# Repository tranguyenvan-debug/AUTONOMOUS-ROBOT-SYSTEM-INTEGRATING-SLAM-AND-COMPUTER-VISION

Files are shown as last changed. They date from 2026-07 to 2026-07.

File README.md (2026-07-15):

# 🤖 Autonomous Robot System Integrating SLAM and Computer Vision

**Final Year Project (Đồ Án 2)** — Ho Chi Minh City University of Technology (HCMUT)

Bachelor of Engineering in Electronics and Telecommunications

**Student:** Nguyen Van Tra

**Supervisor:** Assoc. Prof. Dr. Ha Hoang Kha

**Year:** 2026

**Achievement:** 9/10






---

## 📋 Overview

An indoor autonomous mobile robot system built on **ROS2 Jazzy**, integrating:

- 🗺️ **SLAM** — Real-time 360° environment mapping via LiDAR
- 📍 **Localization** — Robot positioning on saved maps (AMCL)
- 🚗 **Navigation** — Autonomous waypoint navigation with obstacle avoidance (Nav2)
- 👁️ **Computer Vision** — Object detection and visual servoing (YOLOv8n)
- 🌐 **Web Dashboard** — Browser-based monitoring and control via WiFi

Prototyte

3D

2D

Web

TFtree

Tele

Schematic

Map

Map_Web

AI

---

## 🖼️ Hardware Gallery

<div align="center">

| Component | Image |
|:---:|:---:|
| Raspberry Pi 4 (4GB) | Pi4 |
| ESP32 DevKit v1 | ESP32 |
| RPLidar A1M8 | LiDAR A1M8 |
| Raspberry Pi Camera V2 | Camera Pi V2 |
| MPU6050 IMU | IMU |
| JGB37-520 Motor w/ Encoder | JGB37-520-Encoder |
| L298N Motor Driver | Drive L298N |
| Buck DC-DC | Buck DC |
| BMS | BMS |
| 12V Power (3S 18650) |  |

</div>

---

## 🔧 Hardware Components

<div align="center">

| Component | Model | Role |
|:---:|:---:|:---:|
| Embedded Computer | Raspberry Pi 4 (4GB RAM) | ROS2, SLAM, Nav2, AI processing |
| Microcontroller | ESP32 DevKit v1 | PID motor control, Odometry |
| LiDAR | RPLidar A1M8 | 360° environment scanning, 12m range |
| Camera | Raspberry Pi Camera V2 | Video stream, object detection |
| IMU | MPU6050 | Acceleration & angular velocity |
| Motors | JGB37-520 12V w/ Encoder | Differential drive |
| Motor Driver | L298N H-Bridge | DC motor control |
| Power | 12V 18650 Battery | Main power supply |

</div>

---

## 🔌 Pin Wiring Table

### ESP32 → L298N (Motor Driver)

<div align="center">

| ESP32 Pin | L298N Pin | Description |
|:---:|:---:|:---:|
| GPIO 25 | IN1 | Left motor direction A |
| GPIO 26 | IN2 | Left motor direction B |
| GPIO 27 | IN3 | Right motor direction A |
| GPIO 14 | IN4 | Right motor direction B |
| GPIO 32 | ENA (PWM) | Left motor speed |
| GPIO 33 | ENB (PWM) | Right motor speed |
| GND | GND | Common ground |

</div>

### ESP32 → Encoder (JGB37-520)

<div align="center">

| ESP32 Pin | Encoder Pin | Description |
|:---:|:---:|:---:|
| GPIO 18 | Left Encoder A | Left wheel channel A |
| GPIO 19 | Left Encoder B | Left wheel channel B |
| GPIO 22 | Right Encoder A | Right wheel channel A |
| GPIO 23 | Right Encoder B | Right wheel channel B |
| 3.3V | VCC | Encoder power |
| GND | GND | Common ground |

</div>

### Raspberry Pi 4 → MPU6050 (I2C)

<div align="center">

| Raspberry Pi Pin | MPU6050 Pin | Description |
|:---:|:---:|:---:|
| Pin 1 (3.3V) | VCC | Power supply |
| Pin 6 (GND) | GND | Ground |
| Pin 3 (GPIO 2, SDA) | SDA | I2C data |
| Pin 5 (GPIO 3, SCL) | SCL | I2C clock |
| — | AD0 | Left floating → address 0x68 |

</div>

### Raspberry Pi 4 → Other Peripherals

<div align="center">

| Raspberry Pi | Device | Interface |
|:---:|:---:|:---:|
| USB Port 1 | ESP32 | USB Serial (/dev/ttyESP32) |
| USB Port 2 | RPLidar A1M8 | USB Serial (/dev/ttyLIDAR) |
| CSI Camera Port | Pi Camera V2 | CSI Ribbon Cable |

</div>

---

## 💻 Software Stack

<div align="center">

| Component | Technology |
|:---:|:---:|
| OS | Ubuntu 24.04 (Raspberry Pi) |
| Framework | ROS2 Jazzy |
| SLAM | SLAM Toolbox (Graph-based SLAM) |
| Localization | AMCL (Adaptive Monte Carlo) |
| Navigation | Nav2 Stack (MPPI + NavFn/A*) |
| Sensor Fusion | EKF (robot_localization) |
| AI Model | YOLOv8n ONNX (80 classes, COCO) |
| Web Frontend | HTML/JavaScript + roslibjs |
| Web Backend | Python HTTP Server |
| Notification | Telegram Bot API |

</div>

---

## 📁 Project Structure

```
robot_project/
├── robot_ws/src/robot_base/
│   ├── robot_base/
│   │   ├── serial_bridge.py        # ESP32 communication via Serial USB
│   │   ├── imu_publisher.py        # MPU6050 IMU reading via I2C
│   │   ├── camera_publisher.py     # Pi Camera V2 stream (OpenCV)
│   │   └── yolo_detector.py        # YOLOv8n detection + Visual Servoing
│   ├── launch/
│   │   ├── slam.launch.py          # Boot: start base nodes
│   │   ├── slam_only.launch.py     # SLAM Toolbox (mapping mode)
│   │   └── nav2_only.launch.py     # Nav2 Stack (navigation mode)
│   └── config/
│       ├── ekf.yaml                # Extended Kalman Filter config
│       ├── slam.yaml               # SLAM Toolbox parameters
│       └── nav2_params.yaml        # Nav2 config (AMCL, costmap, planner)
├── robot_web/
│   ├── backend.py                  # HTTP server (port 8080)
│   └── index.html                  # Web Dashboard
├── maps/                           # Saved maps (.pgm, .yaml, waypoints.json)
├── yolov8n.onnx                    # AI model (12.7MB)
├── run_slam.sh                     # SLAM startup script
├── run_nav2.sh                     # Nav2 startup script
├── send_ip.sh                      # Send IP via Telegram on boot
├── docs/images/                    # Hardware photos (add yours here)
└── /etc/
    ├── systemd/system/
    │   ├── robot-ros.service       # Auto-start ROS2 on boot
    │   └── robot-web.service       # Auto-start Web Dashboard on boot
    └── udev/rules.d/
        └── 99-robot.rules          # Fixed port symlinks for ESP32 & LiDAR
```

---

## ⬇️ Download

### Option 1 — Download from GitHub Releases (Recommended)

1. Go to the [**Releases**](../../releases) tab on GitHub
2. Download the latest `.zip` file (e.g. `AUTONOMOUS-ROBOT-SYSTEM-INTEGRATING-SLAM-AND-COMPUTER-VISION-1.0.0.zip`)
3. Extract and follow the installation steps below

### Option 2 — Clone via Git

```bash
git clone https://github.com/tranguyenvan-debug/AUTONOMOUS-ROBOT-SYSTEM-INTEGRATING-SLAM-AND-COMPUTER-VISION
cd AUTONOMOUS-ROBOT-SYSTEM-INTEGRATING-SLAM-AND-COMPUTER-VISION-1.0.0
```

### Option 3 — Download ZIP directly

Click **Code → Download ZIP** at the top of this page.

---

## 🚀 Installation

### Requirements

- Raspberry Pi 4 (Ubuntu 24.04)
- ROS2 Jazzy
- Python 3.12+

### 1. Install ROS2 Jazzy

```bash
# Follow official guide
https://docs.ros.org/en/jazzy/Installation/Ubuntu-Install-Debs.html
```

### 2. Install dependencies

```bash
sudo apt install -y \
  ros-jazzy-slam-toolbox \
  ros-jazzy-nav2-bringup \
  ros-jazzy-robot-localization \
  ros-jazzy-rosbridge-server \
  ros-jazzy-rplidar-ros \
  ros-jazzy-nav2-mppi-controller

pip install onnxruntime opencv-python smbus2 pyserial --break-system-packages
```

### 3. Clone and build

```bash
mkdir -p ~/robot_ws/src
cd ~/robot_ws/src
git clone https://github.com/tranguyenvan-debug/AUTONOMOUS-ROBOT-SYSTEM-INTEGRATING-SLAM-AND-COMPUTER-VISION
cd ~/robot_ws
colcon build --packages-select robot_base
source install/setup.bash
```

### 4. Setup udev rules (fixed serial ports)

```bash
sudo cp etc/udev/rules.d/99-robot.rules /etc/udev/rules.d/
sudo udevadm control --reload-rules && sudo udevadm trigger
# Verify: ls -la /dev/ttyESP32 /dev/ttyLIDAR
```

### 5. Install systemd services (auto-boot)

```bash
sudo cp etc/systemd/system/robot-ros.service /etc/systemd/system/
sudo cp etc/systemd/system/robot-web.service /etc/systemd/system/
sudo systemctl enable robot-ros.service robot-web.service
sudo systemctl start robot-ros.service robot-web.service
```

### 6. Configure Telegram Bot (receive IP on boot)

Edit `send_ip.sh`:
```bash
TOKEN="your_bot_token_here"
CHAT_ID="your_chat_id_here"
```

Get your token from [@BotFather](https://t.me/botfather) on Telegram.

---

## 📖 Usage

### Access Web Dashboard

```
http://<raspberry_pi_ip>:8080
```

> 💡 The robot sends its IP to your Telegram on every boot — no need to check manually.

### Operating Flow

```
1. Power on Pi → services auto-start → receive IP via Telegram
2. Open Web Dashboard in browser
3. Tab [Mapping]:
   - Click "Start SLAM"
   - Drive robot around the room using joystick
   - Click "Save Map" → enter name → "Stop SLAM"
4. Tab [Navigation]:
   - Click "Start Nav2" (wait ~30s for initialization)
   - Click "Set Initial Pose" (place robot at starting position)
   - Save waypoints → click any waypoint to start autonomous navigation
5. Tab [AI]:
   - Click "Start AI"
   - Camera shows real-time object detection
   - Click object name to activate visual servoing (robot follows target)
```

---

## 🌐 Web Dashboard

<div align="center">

| Tab | Features |
|:---:|:---:|
| **Mapping** | Real-time SLAM map, joystick control, emergency stop, save map |
| **Navigation** | Autonomous waypoint navigation, robot position on map, camera feed |
| **AI** | Live camera, YOLOv8n detection overlay, visual servoing target selection |
| **History** | Trip log, obstacle count, distance traveled, system stats |

</div>

### Backend API Endpoints

<div align="center">

| Endpoint | Description |
|:---:|:---:|
| `GET /slam/start` | Start SLAM mapping |
| `GET /slam/stop` | Stop SLAM |
| `GET /nav2/start` | Start Nav2 (loads latest map) |
| `GET /nav2/stop` | Stop Nav2 |
| `GET /map/save?name=X` | Save current map |
| `GET /waypoint/save` | Save current position as waypoint |
| `GET /waypoint/list` | List all waypoints for current map |
| `GET /waypoint/delete` | Delete a waypoint |
| `GET /ai/start` | Start YOLO detector |
| `GET /ai/stop` | Stop YOLO detector |
| `GET /set_initial_pose` | Publish initial pose to AMCL |
| `GET /sysinfo` | CPU / RAM / Disk / WiFi stats |
| `GET /status` | SLAM / Nav2 running status |

</div>

---

## 📊 Technical Specifications

### AI Model — YOLOv8n

<div align="center">

| Parameter | Value |
|:---:|:---:|
| Model | YOLOv8n (Nano) |
| Format | ONNX Runtime |
| Number of classes | 80 (COCO dataset) |
| Model size | 12.7 MB |
| mAP50 (COCO) | 37.3% |
| mAP50-95 (COCO) | 52.9% |
| FPS on Raspberry Pi 4 | ~0.3–0.5 FPS |
| Confidence threshold | 0.4 |
| IoU threshold (NMS) | 0.45 |

</div>

### Navigation — Nav2

<div align="center">

| Parameter | Value |
|:---:|:---:|
| Global Planner | NavFn (A*) |
| Local Planner | MPPI Controller |
| Robot radius | 0.15 m |
| Inflation radius | 0.2 m |
| Max linear velocity | 0.2 m/s |
| Goal tolerance | 0.5 m |
| Map resolution | 0.02 m/pixel |

</div>

### LiDAR — RPLidar A1M8

<div align="center">

| Parameter | Value |
|:---:|:---:|
| Range | 0.15 — 12 m |
| Scan frequency | ~5.5 Hz (360°/revolution) |
| Points per scan | ~1,450 points |
| Interface | USB Serial |

</div>

---

## 🐛 Debugging

```bash
# Check running nodes
ros2 node list

# Check SLAM status
ros2 lifecycle get /slam_toolbox

# Check AMCL pose
ros2 topic echo /amcl_pose --once

# Check LiDAR data rate
ros2 topic hz /scan

# View service logs
sudo journalctl -u robot-ros.service -f
sudo journalctl -u robot-web.service -f

# Restart all services
sudo systemctl restart robot-ros.service robot-web.service

# Fix port conflict (rosbridge)
sudo fuser -k 9090/tcp

# Check CPU load
top -bn1 | head -5
```

---

## 📚 References

- [ROS2 Jazzy Documentation](https://docs.ros.org/en/jazzy/)
- [Nav2 Documentation](https://docs.nav2.org/)
- [SLAM Toolbox](https://slam-toolbox.readthedocs.io/)
- [YOLOv8 — Ultralytics](https://docs.ultralytics.com/models/yolov8/)
- [ONNX Runtime](https://onnxruntime.ai/docs/)
- [Probabilistic Robotics — Thrun, Burgard, Fox](http://www.probabilistic-robotics.org/)
- [Telegram Bot API](https://core.telegram.org/bots/api)

---

## 📄 License

MIT License — Free to use for educational and research purposes.

---

## ⭐ Support This Project

If this project helped you or inspired your own robot build, please consider giving it a **star** ⭐ on GitHub — it means a lot and helps others discover this project!

<div align="center">

**Made with ❤️ by [nguyenvantra-debug](https://github.com/nguyenvantra-debug) (Văn Trà)**

*Ho Chi Minh City University of Technology (HCMUT) | Bachelor of Engineering in Electronics and Telecommunications | 2026*

</div>

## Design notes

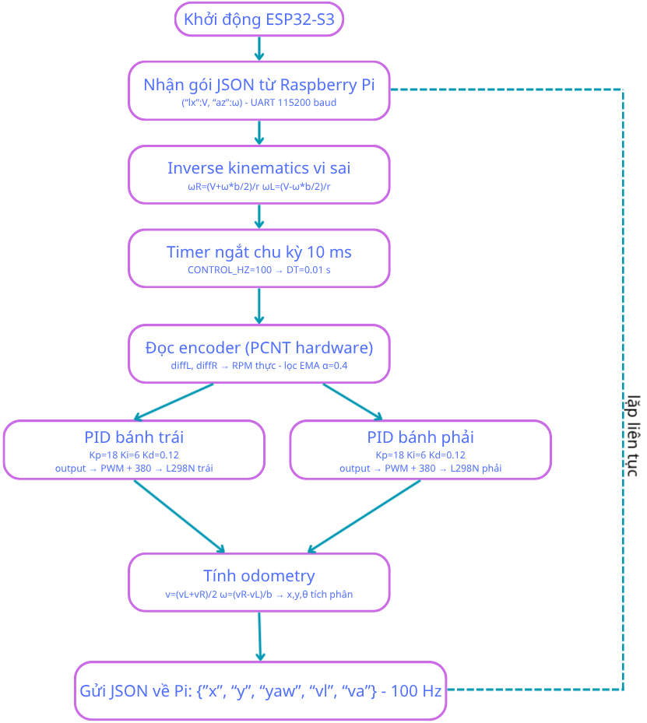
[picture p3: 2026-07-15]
System Block Diagram/Picture7.png

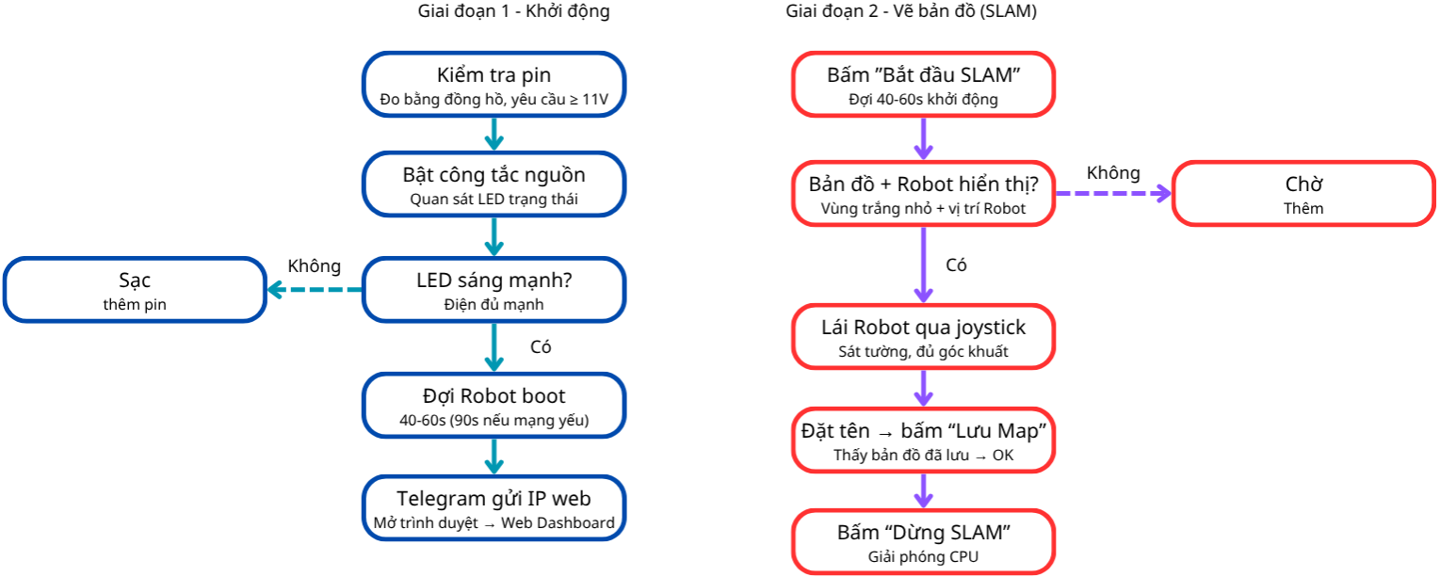
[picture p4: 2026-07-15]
System Block Diagram/Picture11.png

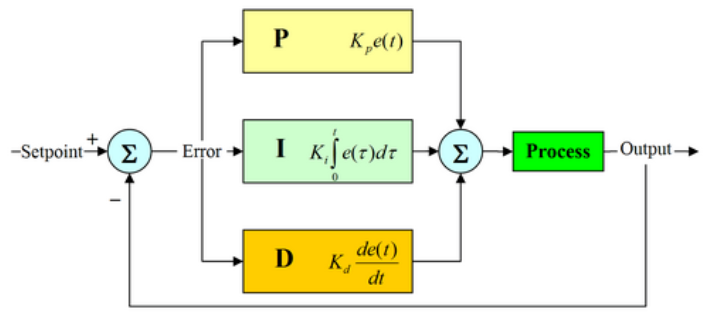
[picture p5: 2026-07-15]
System Block Diagram/Picture2.png

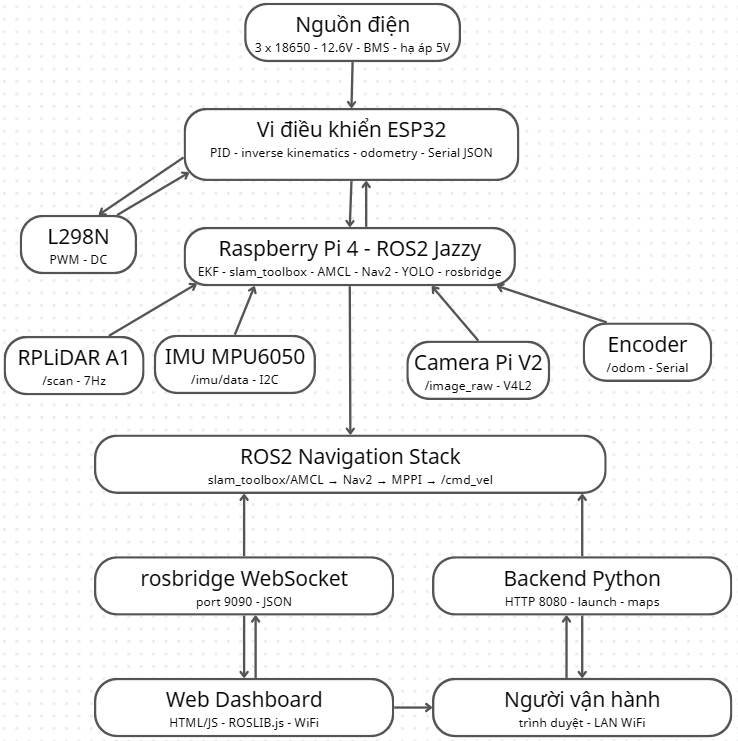
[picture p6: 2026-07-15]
System Block Diagram/Picture4.png

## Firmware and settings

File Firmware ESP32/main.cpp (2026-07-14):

#include <Arduino.h>
#include <ArduinoJson.h>
#include <ESP32Encoder.h>

// ================= PIN =================
#define L_IN1 5
#define L_IN2 6
#define L_PWM 4

#define R_IN1 15
#define R_IN2 7
#define R_PWM 16

#define L_A 9
#define L_B 8
#define R_A 11
#define R_B 10

#define LED_PIN 2

#define PWM_FREQ 800
#define PWM_RES 10
#define PWM_MAX 1023
#define PWM_MIN 380

#define L_CH 0
#define R_CH 1

// ================= ROBOT =================
const float wheel_diameter = 0.065;
const float wheel_base = 0.18;
const float wheel_circ = PI * wheel_diameter;

const float PPR_L = 10800.0;
const float PPR_R = 11330.0;

// ================= CONTROL =================
#define CONTROL_HZ 100
#define DT (1.0 / CONTROL_HZ)

// ================= ENCODER =================
ESP32Encoder encL;
ESP32Encoder encR;

long prevTickL = 0;
long prevTickR = 0;

// ================= CMD =================
float cmd_v = 0;
float cmd_w = 0;

float cmd_v_ramp = 0;
float cmd_w_ramp = 0;

uint32_t lastCmd = 0;
const uint32_t timeout = 500;

// ================= TARGET RPM =================
float targetRPM_L = 0;
float targetRPM_R = 0;

// ================= PID =================
float Kp = 18;
float Ki = 6;
float Kd = 0.12;

float eL = 0, eR = 0;
float prevL = 0, prevR = 0;
float sumL = 0, sumR = 0;

// ================= FILTER =================
float rpmL_f = 0;
float rpmR_f = 0;
const float alpha = 0.4;

// ================= ODOM =================
float x = 0;
float y = 0;
float th = 0;

// ================= MOTOR =================
void setDir(float L, float R) {

  if (L > 0) {
    digitalWrite(L_IN1, LOW);
    digitalWrite(L_IN2, HIGH);
  }
  else if (L < 0) {
    digitalWrite(L_IN1, HIGH);
    digitalWrite(L_IN2, LOW);
  }
  else {
    digitalWrite(L_IN1, LOW);
    digitalWrite(L_IN2, LOW);
  }

  if (R > 0) {
    digitalWrite(R_IN1, LOW);
    digitalWrite(R_IN2, HIGH);
  }
  else if (R < 0) {
    digitalWrite(R_IN1, HIGH);
    digitalWrite(R_IN2, LOW);
  }
  else {
    digitalWrite(R_IN1, LOW);
    digitalWrite(R_IN2, LOW);
  }
}

void setPWM(int L, int R) {

  if (L != 0)
    L = constrain(abs(L) + PWM_MIN, PWM_MIN, PWM_MAX);

  if (R != 0)
    R = constrain(abs(R) + PWM_MIN, PWM_MIN, PWM_MAX);

  ledcWrite(L_CH, L);
  ledcWrite(R_CH, R);
}

// ================= RAMP =================
float ramp(float current, float target, float step) {

  float diff = target - current;

  if (diff > step) diff = step;
  if (diff < -step) diff = -step;

  return current + diff;
}

// ================= RECEIVE CMD =================
void readCmd() {

  if (!Serial.available()) return;

  String json = Serial.readStringUntil('\n');

  StaticJsonDocument<64> doc;

  if (!deserializeJson(doc, json)) {

    cmd_v = doc["lx"] | 0.0;
    cmd_w = doc["az"] | 0.0;

    lastCmd = millis();
  }
}

// ================= VELOCITY =================
void velocityLoop() {

  float step = 0.5 * DT;

  cmd_v_ramp = ramp(cmd_v_ramp, cmd_v, step);
  cmd_w_ramp = ramp(cmd_w_ramp, cmd_w, step);

  float vL = cmd_v_ramp - cmd_w_ramp * wheel_base / 2;
  float vR = cmd_v_ramp + cmd_w_ramp * wheel_base / 2;

  targetRPM_L = (vL / wheel_circ) * 60;
  targetRPM_R = (vR / wheel_circ) * 60;
}

// ================= RPM =================
float calcRPM(long diff, float ppr) {
  return (diff / ppr) * 60.0 * CONTROL_HZ;
}

// ================= CONTROL LOOP =================
void controlLoop() {

  static uint32_t last = 0;

  if (millis() - last < 1000 / CONTROL_HZ)
    return;

  last = millis();

  // ===== EMERGENCY STOP =====
  if (millis() - lastCmd > timeout) {

    cmd_v = 0;
    cmd_w = 0;

    cmd_v_ramp = 0;
    cmd_w_ramp = 0;

    targetRPM_L = 0;
    targetRPM_R = 0;
  }

  long tickL = encL.getCount();
  long tickR = encR.getCount();

  long diffL = tickL - prevTickL;
  long diffR = tickR - prevTickR;

  prevTickL = tickL;
  prevTickR = tickR;

  float rpmL = calcRPM(diffL, PPR_L);
  float rpmR = calcRPM(diffR, PPR_R);

  rpmL_f = alpha * rpmL + (1 - alpha) * rpmL_f;
  rpmR_f = alpha * rpmR + (1 - alpha) * rpmR_f;

  eL = targetRPM_L - rpmL_f;
  eR = targetRPM_R - rpmR_f;

  sumL += eL * DT;
  sumR += eR * DT;

  sumL = constrain(sumL, -200, 200);
  sumR = constrain(sumR, -200, 200);

  float dL = (eL - prevL) / DT;
  float dR = (eR - prevR) / DT;

  float outL = Kp * eL + Ki * sumL + Kd * dL;
  float outR = Kp * eR + Ki * sumR + Kd * dR;

  prevL = eL;
  prevR = eR;

  setDir(outL, outR);
  setPWM(outL, outR);

  // ================= ODOM =================

  float vL = rpmL_f * wheel_circ / 60;
  float vR = rpmR_f * wheel_circ / 60;

  float v = (vL + vR) / 2;
  float w = (vR - vL) / wheel_base;

  th += w * DT;

  x += v * cos(th) * DT;
  y += v * sin(th) * DT;

  // ===== SEND JSON FOR ROS2 =====
  Serial.print("{\"x\":");
  Serial.print(x,4);
  Serial.print(",\"y\":");
  Serial.print(y,4);
  Serial.print(",\"yaw\":");
  Serial.print(th,4);
  Serial.print(",\"vl\":");
  Serial.print(v,4);
  Serial.print(",\"va\":");
  Serial.print(w,4);
  Serial.println("}");

  // ===== DEBUG LED =====
  static uint32_t lastLED = 0;

  if (millis() - lastLED > 500) {
    digitalWrite(LED_PIN, !digitalRead(LED_PIN));
    lastLED = millis();
  }
}

// ================= SETUP =================
void setup() {

  Serial.begin(115200);

  pinMode(L_IN1, OUTPUT);
  pinMode(L_IN2, OUTPUT);
  pinMode(R_IN1, OUTPUT);
  pinMode(R_IN2, OUTPUT);

  pinMode(LED_PIN, OUTPUT);

  ledcSetup(L_CH, PWM_FREQ, PWM_RES);
  ledcAttachPin(L_PWM, L_CH);

  ledcSetup(R_CH, PWM_FREQ, PWM_RES);
  ledcAttachPin(R_PWM, R_CH);

  encL.attachFullQuad(L_B, L_A);
  encR.attachFullQuad(R_A, R_B);

  encL.clearCount();
  encR.clearCount();

  Serial.println("ESP32 ROBOT READY (ROS2 JSON)");
}

// ================= LOOP =================
void loop() {

  readCmd();

  velocityLoop();

  controlLoop();
}

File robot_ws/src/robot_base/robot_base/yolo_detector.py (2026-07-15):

import rclpy
from rclpy.node import Node
from sensor_msgs.msg import CompressedImage
from std_msgs.msg import String
from geometry_msgs.msg import Twist
import cv2
import numpy as np
import json
import onnxruntime as ort
import time
import threading

CLASSES = ['person','bicycle','car','motorcycle','airplane','bus','train','truck','boat',
           'traffic light','fire hydrant','stop sign','parking meter','bench','bird','cat',
           'dog','horse','sheep','cow','elephant','bear','zebra','giraffe','backpack',
           'umbrella','handbag','tie','suitcase','frisbee','skis','snowboard','sports ball',
           'kite','baseball bat','baseball glove','skateboard','surfboard','tennis racket',
           'bottle','wine glass','cup','fork','knife','spoon','bowl','banana','apple',
           'sandwich','orange','broccoli','carrot','hot dog','pizza','donut','cake','chair',
           'couch','potted plant','bed','dining table','toilet','tv','laptop','mouse',
           'remote','keyboard','cell phone','microwave','oven','toaster','sink','refrigerator',
           'book','clock','vase','scissors','teddy bear','hair drier','toothbrush']

class YoloDetector(Node):
    def __init__(self):
        super().__init__('yolo_detector')
        self.sess = ort.InferenceSession('/home/vantra/yolov8n.onnx')
        self.input_name = self.sess.get_inputs()[0].name
        self.sub = self.create_subscription(CompressedImage, '/image_raw/compressed', self.callback, 10)
        self.pub_img = self.create_publisher(CompressedImage, '/detection/compressed', 10)
        self.pub_json = self.create_publisher(String, '/detection/objects', 10)
        self.cmd_pub = self.create_publisher(Twist, '/cmd_vel', 10)
        self.sub_track = self.create_subscription(String, '/track/target', self.set_track, 10)
        self.lock = threading.Lock()
        self.latest_frame = None
        self.last_objects = []
        self.track_class = None
        self.last_yolo_time = 0
        self.lost_time = None
        threading.Thread(target=self.yolo_loop, daemon=True).start()
        self.get_logger().info('YOLO Detector started')

    def set_track(self, msg):
        with self.lock:
            self.track_class = msg.data if msg.data != '' else None
        self.get_logger().info(f'Track: {self.track_class}')

    def preprocess(self, frame):
        img = cv2.resize(frame, (640, 640))
        img = cv2.cvtColor(img, cv2.COLOR_BGR2RGB).astype(np.float32) / 255.0
        return np.expand_dims(np.transpose(img, (2, 0, 1)), 0)

    def yolo_detect(self, frame):
        h, w = frame.shape[:2]
        inp = self.preprocess(frame)
        output = self.sess.run(None, {self.input_name: inp})
        pred = output[0][0].T
        boxes, scores_list, class_ids = [], [], []
        for det in pred:
            scores = det[4:]
            cls = int(np.argmax(scores))
            conf = float(scores[cls])
            if conf < 0.35:
                continue
            cx, cy, bw, bh = det[:4]
            x1 = int((cx - bw/2) * w)
            y1 = int((cy - bh/2) * h)
            x2 = int((cx + bw/2) * w)
            y2 = int((cy + bh/2) * h)
            boxes.append([x1, y1, x2-x1, y2-y1])
            scores_list.append(conf)
            class_ids.append(cls)
        objects = []
        if boxes:
            indices = cv2.dnn.NMSBoxes(boxes, scores_list, 0.35, 0.45)
            if len(indices) > 0:
                for i in indices.flatten():
                    x,y,bw2,bh2 = boxes[i]
                    name = CLASSES[class_ids[i]] if class_ids[i] < len(CLASSES) else str(class_ids[i])
                    objects.append({'name': name, 'conf': round(scores_list[i],2), 'box': [x,y,x+bw2,y+bh2]})
        return objects

    def yolo_loop(self):
        while True:
            time.sleep(1.5)
            with self.lock:
                if self.latest_frame is None:
                    continue
                frame = self.latest_frame.copy()
            objects = self.yolo_detect(frame)
            with self.lock:
                self.last_objects = objects

    def control_robot(self, box, frame_w, frame_h):
        x1,y1,x2,y2 = box
        cx = (x1+x2)/2
        bw = x2-x1
        bh = y2-y1
        area = (bw*bh)/(frame_w*frame_h)
        error_x = (cx - frame_w/2) / (frame_w/2)
        twist = Twist()
        if area > 0.3:
            # Gan roi - dung lai
            twist.linear.x = 0.0
            twist.angular.z = 0.0
        elif abs(error_x) > 0.3:
            # Lech nhieu - xoay cham, tien cham
            twist.linear.x = 0.03
            twist.angular.z = -error_x * 0.3
        elif abs(error_x) > 0.1:
            # Lech vua - tien va chinh nhe
            twist.linear.x = 0.06
            twist.angular.z = -error_x * 0.2
        else:
            # Thang - chi tien
            twist.linear.x = 0.08
            twist.angular.z = 0.0
        self.cmd_pub.publish(twist)

    def callback(self, msg):
        np_arr = np.frombuffer(msg.data, np.uint8)
        frame = cv2.imdecode(np_arr, cv2.IMREAD_COLOR)
        if frame is None:
            return
        h, w = frame.shape[:2]
        with self.lock:
            self.latest_frame = frame.copy()
            objects = list(self.last_objects)
            track_class = self.track_class

        # Vẽ tất cả vật thể
        for o in objects:
            x1,y1,x2,y2 = o['box']
            cv2.rectangle(frame, (x1,y1), (x2,y2), (0,255,0), 1)
            label = f'{o["name"]} {o["conf"]:.2f}'
            (tw,th),_ = cv2.getTextSize(label, cv2.FONT_HERSHEY_SIMPLEX, 0.5, 1)
            cv2.rectangle(frame, (x1,y1-th-6), (x1+tw+4,y1), (0,255,0), -1)
            cv2.putText(frame, label, (x1+2,y1-4), cv2.FONT_HERSHEY_SIMPLEX, 0.5, (0,0,0), 1)
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
